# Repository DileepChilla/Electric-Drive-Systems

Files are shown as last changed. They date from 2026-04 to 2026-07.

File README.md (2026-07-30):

# 24 V / 250 W Brushed DC Motor Driver

**IR2104 half-bridge · 2× IRFZ44N · ATmega328P closed-loop control**

Design, simulation, PCB layout, firmware and bench validation of a complete motor
drive for a MY1016 24 V 250 W brushed DC motor. Built for ELT10140 *Electric Drive
Systems*, Westsächsische Hochschule Zwickau, summer semester 2026.

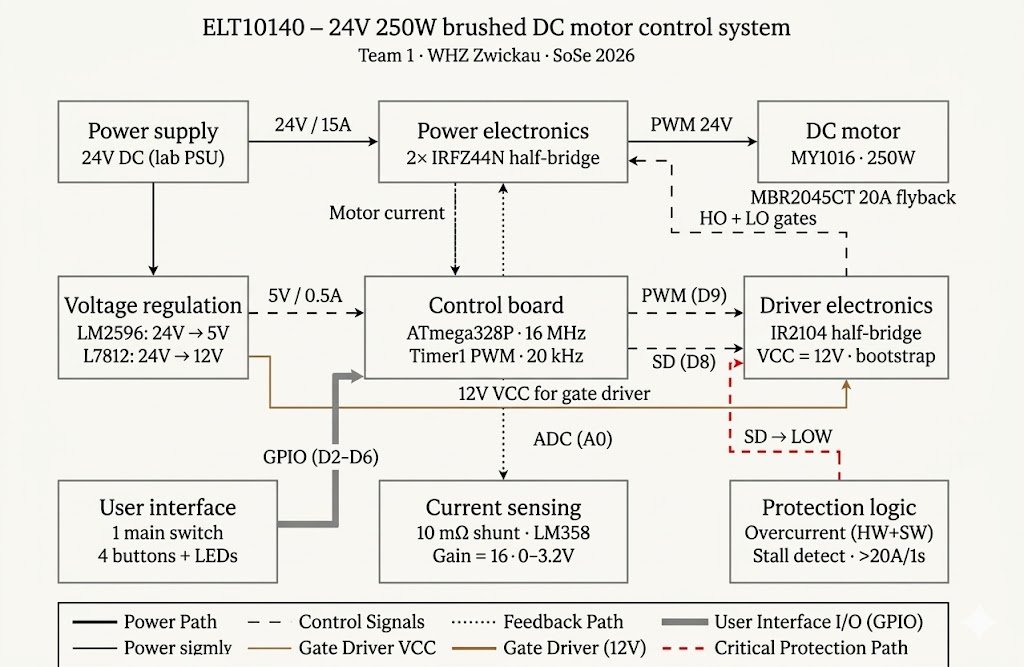
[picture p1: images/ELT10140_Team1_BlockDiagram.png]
Block diagram


---

## What this is

A single-quadrant (unidirectional) drive with hardware and software overcurrent
protection, soft-start, stall detection and a five-state supervisory state machine.
The design was carried through the full V-cycle: analytical sizing → SPICE/VSM
co-simulation → averaged-model verification in Simulink → PCB layout → assembly →
bench test.

| Metric | Value |
|---|---|
| Supply | 24 V DC, 15 A fused |
| Rated output | 250 W |
| Switching frequency | 20 kHz (Timer1 Fast PWM, ICR1 top) |
| Duty resolution | 10 bit (ICR1 = 799 @ 16 MHz, /1 prescaler) |
| Current sense | 10 mΩ shunt, ×16 non-inverting, 0–31 A → 0–5 V |
| Overcurrent trip | Hardware SD assert + firmware stall detect (> 20 A for > 1 s) |
| Board | 2-layer FR-4, 1.55 mm, 35 µm Cu |

---

## Architecture

```
24 V ──┬── LM2596 buck ──── 5 V ──── ATmega328P (Arduino Nano)
       │                                  │ OC1A (D9) ──► IN
       ├── L7812CV linear ── 12 V ────► IR2104 ──┬──► HO ──► Q1 (IRFZ44N, high side)
       │                                  ▲      └──► LO ──► Q2 (IRFZ44N, low side)
       │                            SD ───┘
       │                          (D8 + hardware fault)
       │
       └── power rail ──► Q1 drain
                          switch node ──► MY1016 motor ──► MBR2045CT ──► shunt ──► GND
                                                                          │
                                                          LM358 ×16 ──► ADC0 (A0)
```

### Design decisions worth defending

**IR2104 VCC must be 12 V, not 24 V and not 5 V.**
The device UVLO sits at ~8.2 V rising, so 5 V logic rails cannot drive it; 24 V exceeds
its absolute maximum. A dedicated L7812CV linear regulator supplies VCC. This is the
single most common way to destroy an IR2104 and the reason the design carries a second
regulator despite the buck already producing 5 V.

**Bootstrap sizing.**
1 µF ceramic + 1N4148 fast diode. At 20 kHz the high-side gate charge (Q_g ≈ 63 nC for
IRFZ44N) is replenished every 50 µs; the capacitor must hold V_BS above the 8.0 V
bootstrap UVLO across the maximum on-time. Minimum duty is clamped in firmware so the
low-side device always conducts long enough to recharge.

**Synchronous rectification over a plain flyback diode.**
Q2's channel resistance (17.5 mΩ) dissipates less than the forward drop of the Schottky
during freewheeling. The MBR2045CT remains as a parallel path covering the dead time
and as a fail-safe if the low-side gate drive is lost.

**20 kHz PWM.**
Above the audible band, below the point where IRFZ44N switching losses become the
dominant thermal term (≈ 0.35 W per device at rated current with 10 Ω gate resistors).

**Two independent overcurrent layers.**
Hardware pulls SD low in sub-microsecond time — fast enough for a short circuit.
Firmware stall detection acts on the filtered ADC current over a 1 s window — slow, but
it distinguishes a genuine mechanical jam from inrush. Neither alone is sufficient.

---

## Repository layout

```
├── firmware/          Arduino/AVR source — PWM, ADC, state machine, protection
├── hardware/
│   ├── kicad/         KiCad 10 project: schematic, PCB, footprints
│   ├── gerbers/       Fabrication output + drill files
│   └── datasheets/    Component datasheets referenced in the design
├── simulation/
│   ├── proteus/       Proteus VSM mixed-signal co-simulation (.pdsprj)
│   ├── simulink/      Averaged-model plant + discrete state machine (.slx)
│   └── results/       Captured waveforms, step responses, fault traces
├── design/            Engineering notes and derivations
├── report/            Final report (PDF) and presentation
├── bom/               Bill of materials (CSV + PDF)
└── images/            Diagrams, board photos, schematic exports
```

---

## Firmware

Bare-register AVR C++, no Arduino `analogWrite`. Timer1 in Fast PWM mode 14
(TOP = ICR1) gives a fixed 20 kHz carrier with 10-bit duty resolution.

State machine:

```
OFF ──start──► STARTING ──ramp complete──► RUNNING
 ▲                 │                          │
 │                 └──────overcurrent─────────┤
 │                                            │
 └── BRAKING ◄── stop ──────────────────────► FAULT
```

- `STARTING` ramps duty linearly to limit inrush through the motor's armature inductance.
- `FAULT` latches: SD is driven low and the state persists until an explicit reset.
- `BRAKING` shorts the armature through Q2 for dynamic braking.
- Current is read in a 4-sample exponential moving average to reject switching noise
  without adding the phase lag of a long boxcar filter.

Build: Arduino IDE or PlatformIO, target `nanoatmega328new`, 16 MHz.

---

## Simulation

**Proteus VSM** — the only tool in the chain that runs the compiled firmware against a
SPICE model of the analog stage simultaneously. Used to verify gate drive timing,
bootstrap charging, and that the ADC path actually produces the expected count for a
known shunt current.

> Note: Proteus *Analogue Analysis* is pure SPICE and does not execute the MCU
> firmware. Mixed-signal capture requires the VSM Oscilloscope instrument.
> AREF (ATmega328P pin 20) must be tied to +5 V or every ADC read returns zero and the
> overcurrent path silently fails.

**Simulink** — `MotorDriverAveraged.slx` replaces the switching stage with a duty-cycle
averaged model, letting the electrical (R–L–back-EMF) and mechanical (J–B–T_load)
dynamics run at reasonable step sizes. The firmware state machine is reimplemented in a
discrete MATLAB Function block, together with 10-bit ADC quantisation and the LM358
scaling, so the simulated controller sees the same numbers the real one does.

Two validated scenarios: light-load run-and-brake, and a rotor jam triggering the fault
path.

*Known limitation:* the load-torque model is constant rather than velocity-dependent, so
after a fault the plant shows a small reverse rotation that the real machine does not.
Documented rather than hidden — fixing it requires a Coulomb-friction/zero-speed
constraint on the mechanical block.

---

## Bill of materials

Full BOM in `bom/`. Principal parts:

| Ref | Part | Function |
|---|---|---|
| M1 | MY1016 | 24 V 250 W brushed DC motor |
| U1 | IR2104 | Half-bridge gate driver, bootstrap high-side |
| Q1, Q2 | IRFZ44N | 55 V / 49 A N-channel MOSFET, R_DS(on) 17.5 mΩ |
| D2 | MBR2045CT | 20 A Schottky freewheeling diode |
| U2 | LM358 | Current-sense amplifier, gain 16 |
| U4 | LM2596 module | 24 V → 5 V switching regulator |
| U5 | L7812CV | 24 V → 12 V linear regulator (IR2104 VCC) |
| D1 | 1N4148 | Bootstrap diode |
| — | SMBJ33A | Transient voltage suppressor, input protection |
| R_sh | 10 mΩ, 3 W | Current-sense shunt |

Mechanical: 400 × 300 × 12 mm birch plywood mounting board, ferrule-crimped
connections throughout.

---

## Reproducing

1. Open `hardware/kicad/` in KiCad 10.0 or later.
2. Flash `firmware/` to an Arduino Nano (ATmega328P, 16 MHz).
3. Supply 24 V through a 15 A fuse. **Confirm the L7812CV output is 12 V before
   connecting IR2104 VCC.**
4. Verify the switch node with an isolated probe before attaching the motor.

---

## Course context

ELT10140 Electric Drive Systems, SoSe 2026 · Westsächsische Hochschule Zwickau
Supervisors: Prof. Dr.-Ing. J. Zitzelsberger, Prof. U. David, Prof. R. Lehmann
Team 1 — Leo Kämpf (team lead), Dileep Chilla (documentation, simulation, PCB),
Vaibhav, Rahul, Shashank, Usman, Vaishali, Laert

Course handouts and lecture material are the property of WHZ and are not redistributed
in this repository.

## Licence

Source code and design files: MIT (see `LICENSE`).
Documentation and figures: CC BY 4.0.

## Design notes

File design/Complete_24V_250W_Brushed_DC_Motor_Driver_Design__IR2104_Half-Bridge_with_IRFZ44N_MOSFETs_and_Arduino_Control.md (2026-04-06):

# Complete 24V 250W brushed DC motor driver design

**The IR2104 + dual IRFZ44N half-bridge forms a synchronous buck topology that delivers clean, efficient PWM drive to the MY1016 motor — but several component-level corrections are critical before building.** The original parts list contains two significant errors: the 1N5822 Schottky diode is rated only 3A (far below the 13.7A motor current), and a single IRFZ44N cannot work with the IR2104, which drives a high-side/low-side MOSFET pair. Additionally, the IR2104 requires **10–20V on its VCC pin**, meaning a dedicated 12V regulator is needed beyond the LM2596 5V module. This report provides every component value, calculation, code listing, and layout rule needed to build an error-free motor driver PCB for the ELT10140 project at WHZ Zwickau.

---

## How the IR2104 half-bridge actually works

The IR2104 is not a simple gate buffer — it is a **complementary half-bridge driver** with built-in 520 ns deadtime. Two N-channel IRFZ44N MOSFETs form the half-bridge: Q1 (high-side, drain to +24V) and Q2 (low-side, source to GND). The motor connects between the switching node (junction of Q1 source and Q2 drain) and ground.

**Operating sequence at each PWM cycle:**

When IN goes HIGH, Q2 turns off first, 520 ns of deadtime passes, then Q1 turns on. Current flows from +24V through Q1 into the motor. When IN goes LOW, Q1 turns off, deadtime passes, then Q2 turns on. The motor's inductive current now freewheels through Q2's channel at very low loss (synchronous rectification). The average motor voltage equals **duty cycle × 24V**, giving smooth, linear speed control from 0 to ~23V.

The SD (shutdown) pin provides emergency stop capability. **SD = HIGH enables the driver; SD = LOW forces both outputs off.** A 10 kΩ pull-down resistor on SD ensures the driver powers up disabled — a critical safety feature the Arduino must explicitly override by driving SD HIGH.

**Pin connections (IR2104 in 8-DIP):**

| Pin | Symbol | Connects to |
|-----|---|---|
| 1 | VCC | +12V regulated supply |
| 2 | IN | Arduino Pin D9 (Timer1 OC1A PWM) |
| 3 | SD | Arduino Pin D8 via 10 kΩ pull-down to GND |
| 4 | COM | Power ground (GND) |
| 5 | LO | Q2 gate through 10 Ω resistor |
| 6 | VS | Switching node (Q1 source / Q2 drain) |
| 7 | HO | Q1 gate through 10 Ω resistor |
| 8 | VB | Bootstrap capacitor to VS; bootstrap diode from VCC |

No level shifting is needed. The IR2104 accepts 5V logic directly (VIH ≥ 3.0V, VIL ≤ 0.8V). Input bias current is just 3–10 µA, negligible for Arduino GPIO.

---

## Complete schematic with every component value

### Power stage

The heart of the circuit is the half-bridge formed by two IRFZ44N MOSFETs. **You need two IRFZ44N devices, not one.** Q1 serves as the high-side switch (drain to +24V, source to switching node), Q2 as the low-side switch (drain to switching node, source to GND through the current sense resistor).

**Bulk capacitor on 24V rail:** 470 µF / 50V electrolytic in parallel with 100 nF / 50V ceramic, placed directly at the power input connector. These handle the high di/dt current pulses during PWM switching. Without them, voltage spikes during switching can exceed the IRFZ44N's 55V drain-source rating.

**Gate resistors:** 10 Ω in series with each gate (between IR2104 HO→Q1 gate and LO→Q2 gate). These damp LC ringing from gate trace inductance and MOSFET input capacitance. Values above 100 Ω slow switching dangerously; values below 5 Ω may cause ringing. A **10 kΩ pull-down resistor from each gate to its respective source** ensures MOSFETs stay off if the IR2104 loses power.

### Bootstrap circuit

The bootstrap circuit charges a capacitor (C_boot) when Q2 is ON (VS pulled to ground), then uses that stored energy to drive Q1's gate above the 24V rail.

**Bootstrap capacitor calculation (worst case):**

The charge consumed per switching cycle includes the IRFZ44N gate charge (Qg = 63 nC max), the IR2104 quiescent VBS current (55 µA max at 20 kHz = 2.75 nC), and level-shift charge (~5 nC). Total per-cycle charge is approximately **71 nC**. The minimum capacitor value follows the formula C_boot ≥ 2 × Q_total / ΔV, where ΔV = VCC − V_diode − V_LS_drop − V_UVLO_min = 12 − 0.5 − 0.24 − 8.2 = 3.06V. This yields C_min ≈ 46 nF. Applying the standard **15× safety factor** gives 690 nF.

**Use a 1 µF ceramic capacitor (MLCC, X7R, 50V rated)** between VB and VS. This value appears consistently across Infineon application notes, verified project implementations, and the AN-978 design guide. Do not use electrolytic capacitors — their ESR and leakage are too high for bootstrap service.

**Bootstrap diode: UF4007** (1000V, 1A, ultra-fast recovery, 75 ns trr). This connects anode to VCC (+12V), cathode to VB. The 1000V rating provides enormous margin over the 24V bus. A fast recovery diode is essential — a slow diode allows charge to flow backward out of the bootstrap capacitor during VS transitions, starving the high-side gate drive. Alternative: MBR160 (60V Schottky) for lower forward voltage drop (0.5V vs 1.0V), though the UF4007's wider voltage margin is preferred for a student project.

The resulting high-side gate voltage is approximately VCC − V_diode_drop = 12 − 0.5 ≈ **11.5V** (with Schottky) or 12 − 1.0 ≈ **11V** (with UF4007). Both fully enhance the IRFZ44N well above the 10V specification point.

**Maximum duty cycle limitation:** The bootstrap capacitor recharges only when Q2 is ON. At 95% duty and 20 kHz (50 µs period), Q2 conducts for 2.5 µs — sufficient to recharge 1 µF through the low-impedance path. At 99%+ duty, on-time drops below 0.5 µs and the capacitor may not fully recharge. **Practical limit: ~95–97% duty cycle.**

### IR2104 VCC supply

The IR2104 requires **10–20V on VCC**. The LM2596 module providing 5V to the Arduino cannot serve this purpose. Add a separate **L7812 (or LM7812) linear regulator**: 24V input → 12V output. Bypass the regulator with 100 nF ceramic on both input and output, plus 10 µF electrolytic on the output. At the IR2104's modest current draw (~1 mA quiescent plus gate charge current), the 7812's dissipation is approximately (24 − 12) × 0.01 ≈ 0.12W — negligible.

**VCC decoupling at the IR2104:** Place a **100 nF ceramic capacitor directly between VCC (pin 1) and COM (pin 4)**, within 5 mm of the IC. Add a **10 µF electrolytic in parallel**, slightly further away. This dual-capacitor arrangement handles both high-frequency switching transients (ceramic) and lower-frequency supply droop (electrolytic).

### Current sensing circuit

A low-side shunt resistor between Q2's source and power ground measures motor current. The voltage across this shunt is amplified by one half of the LM358 dual op-amp.

**Shunt resistor: 10 mΩ (0.010 Ω), rated 5–10W.** Use a metal-strip type (Vishay WSL2512 in 2512 SMD or Ohmite 25FR010 through-hole wirewound). At 13.7A rated current, V_shunt = 137 mV and P_shunt = 1.88W. At 27A stall, P_shunt = 7.29W. A 10W-rated resistor survives brief stalls while overcurrent protection activates.

Why 10 mΩ? Smaller values (1–5 mΩ) produce signals below the LM358's 2–7 mV input offset voltage, causing unacceptable measurement error. Larger values (20+ mΩ) waste power and create significant voltage drops that reduce motor drive voltage.

**LM358 non-inverting amplifier (gain = 16):**

The LM358 has a critical limitation on 5V supply: **its output can only swing to approximately 3.5V maximum** (VCC − 1.5V). The design therefore maps the overcurrent threshold (20A) to 3.2V rather than 5V:

- R1 = **1.0 kΩ** (ground to inverting input)
- R2 = **15 kΩ** (feedback, inverting input to output)
- Gain = 1 + R2/R1 = 1 + 15/1 = **16**
- Use 1% metal film resistors for both

**Transfer function:** V_out = I_motor × 0.010 Ω × 16 = **0.16 × I_motor** (volts). At the Arduino's 10-bit ADC (5V reference): **ADC count = I_motor × 32.77**. Current resolution is approximately **30.5 mA per ADC count** — more than adequate for motor control.

| Motor current | Shunt voltage | LM358 output | ADC count |
|---|---|---|---|
| 0 A | 0 mV | ~0 V | 0 |
| 5 A | 50 mV | 0.80 V | 164 |
| 10 A | 100 mV | 1.60 V | 328 |
| **13.7 A (rated)** | **137 mV** | **2.19 V** | **449** |
| **20 A (OC threshold)** | **200 mV** | **3.20 V** | **655** |
| 22+ A | 220+ mV | Saturates ~3.5 V | ~720 |

Above ~22A the LM358 output clips at 3.5V. This is acceptable because overcurrent protection should trigger at 20A (ADC ≈ 655), well before saturation.

**Output filter:** A 1 kΩ resistor and **82 nF ceramic capacitor** form a low-pass filter (f_c ≈ 1.94 kHz) between the LM358 output and the Arduino analog pin. This removes PWM-frequency ripple while preserving the averaged current signal.

**ADC protection:** Place a 1 kΩ series resistor immediately before the Arduino analog pin, followed by a BAT54S Schottky diode from the pin to the 5V rail (cathode to 5V). This clamps any overvoltage from reaching the ATmega328P.

**Offset calibration:** The LM358's 2–7 mV typical offset, amplified by 16, creates a 32–112 mV output offset (equivalent to 0.2–0.7A error). **Calibrate in software** by reading the ADC at zero motor current during startup and subtracting this baseline.

### Corrected flyback / freewheeling diode

**The 1N5822 Schottky diode is rated only 3A average forward current — it is fundamentally inadequate for a 13.7A motor.** In the half-bridge topology, during the 520 ns deadtime between Q1 turning off and Q2 turning on, the motor's inductive current freewheels through Q2's body diode. An external Schottky diode across Q2 (anode to source/GND, cathode to drain/switching node) provides a lower-loss freewheeling path during deadtime.

**Replace the 1N5822 with an MBR2045CT** (20A, 45V dual Schottky in TO-220) or equivalent. Use one diode of the dual package across Q2. The 20A rating provides margin above the 13.7A operating current, and the 45V rating exceeds the 24V bus with comfortable margin.

The 1N5822 could still serve as the bootstrap diode alternative or for auxiliary protection circuits, but must not carry motor current.

### Buttons and indicators

Use Arduino's internal pull-ups (INPUT_PULLUP) for buttons: connect each button between the GPIO pin and GND. Press reads LOW. Software debounce at 50 ms eliminates bounce without external RC networks.

- **Start button:** Pin D2 → GND
- **Stop button:** Pin D3 → GND  
- **Fault reset button:** Pin D5 → GND

**LED indicators:** Green LED (motor running) on pin D6, red LED (fault) on pin D7, each with a **330 Ω series resistor** to ground. Pin D13's onboard LED serves as a heartbeat indicator.

### Complete bill of materials

| Component | Value / Part | Rating | Purpose |
|---|---|---|---|
| IR2104 | Infineon, 8-DIP | 600V half-bridge driver | Gate driver IC |
| IRFZ44N × **2** | Infineon, TO-220 | 55V, 49A, 17.5 mΩ | High-side and low-side MOSFETs |
| C_boot | 1 µF ceramic MLCC | 50V, X7R | Bootstrap capacitor (VB–VS) |
| D_boot | UF4007 | 1000V, 1A, ultra-fast | Bootstrap diode (VCC→VB) |
| C_VCC_HF | 100 nF ceramic | 25V | IR2104 VCC bypass (close to IC) |
| C_VCC_bulk | 10 µF electrolytic | 25V | IR2104 VCC decoupling |
| C_bus_bulk | 470 µF electrolytic | 50V | 24V bus decoupling |
| C_bus_HF | 100 nF ceramic | 50V | 24V bus HF bypass |
| D_freewheel | **MBR2045CT** | 20A, 45V Schottky | Across Q2 (freewheeling) |
| R_gate × 2 | 10 Ω | ¼W | Series gate resistors |
| R_GS × 2 | 10 kΩ | ¼W | Gate-source pull-downs |
| R_SD | 10 kΩ | ¼W | SD pin pull-down to GND |
| 7812 regulator | L7812CV | 24V→12V, 1A | IR2104 VCC supply |
| C_reg_in | 100 nF ceramic | 50V | 7812 input bypass |
| C_reg_out | 10 µF electrolytic | 25V | 7812 output filter |
| R_shunt | 10 mΩ, metal strip | 5–10W | Current sense resistor |
| LM358 | Dual op-amp, 8-DIP | 5V supply | Current amplifier |
| R1 (gain) | 1.0 kΩ, 1% | ¼W | Amplifier gain network |
| R2 (gain) | 15 kΩ, 1% | ¼W | Amplifier gain network |
| R_filter | 1.0 kΩ | ¼W | Output low-pass filter |
| C_filter | 82 nF ceramic | 25V | Output low-pass filter |
| R_protect | 1.0 kΩ | ¼W | ADC input series protection |
| D_clamp | BAT54S | Schottky clamp | ADC overvoltage protection |
| LM2596 module | 24V→5V buck | 3A | Arduino power supply |
| Buttons × 3 | Tactile switch | — | Start, stop, reset |
| LEDs × 2 | Green, red | 20 mA | Run, fault indicators |
| R_LED × 2 | 330 Ω | ¼W | LED current limiting |

---

## Critical errors that destroy student motor drivers

### The number-one killer: driving IRFZ44N directly from Arduino

The IRFZ44N's VGS(th) of 2–4V is the voltage where conduction *barely begins* — at microamp levels. Full enhancement (17.5 mΩ) requires VGS ≥ 10V. **At VGS = 5V from an Arduino pin, RDS(on) rises to an estimated 100–200 mΩ**, roughly 10× higher than the datasheet value. At 10A, power dissipation jumps from 1.75W to **10–20W** — the MOSFET enters thermal runaway and fails within seconds. The IR2104, powered at 12V VCC, delivers approximately 11–12V to each gate, achieving full enhancement. This is the entire reason a gate driver exists.

If the project requires direct Arduino drive without a gate driver (a simpler approach), replace the IRFZ44N with the **IRLZ44N** (logic-level variant, fully enhanced at VGS = 5V). But with the IR2104 in the design, stick with the standard IRFZ44N.

### Bootstrap failures that cause intermittent operation

Three bootstrap errors account for most IR2104 field failures in student projects. First, **a capacitor below ~100 nF** cannot supply the IRFZ44N's 63 nC gate charge with adequate margin, causing VBS to droop below the 8.2V UVLO threshold. The high-side MOSFET then enters linear mode at partial gate drive, dissipating enormous power. Second, **using a slow-recovery diode** (e.g., 1N4007 instead of UF4007) allows bootstrap charge to leak back into VCC during reverse recovery, depleting the capacitor. Third, **running at 100% duty cycle** prevents Q2 from ever turning on, so the bootstrap capacitor never recharges — the high-side gate drive collapses within milliseconds.

### Decoupling capacitor omissions

Without the 100 nF ceramic directly at VCC (pin 1), the IR2104 experiences voltage transients during gate switching that can trigger false UVLO lockout, causing random gate drive dropouts. Without bulk capacitance (470 µF) on the 24V bus near the MOSFETs, inductive voltage spikes during switching can exceed the IRFZ44N's 55V absolute maximum, causing avalanche breakdown and eventual failure.

### PWM frequency from default analogWrite()

Arduino's `analogWrite()` produces **490 Hz on pins 9/10 and 976 Hz on pins 5/6** — both audibly annoying and electrically poor. Low-frequency PWM creates massive current ripple, increases I²R losses in the motor windings, and causes jerky operation at low speeds. **Always configure Timer1 directly for 20 kHz**, as detailed in the software section below.

### The SD pin left floating

The IR2104's SD pin, if left unconnected, floats at an undefined voltage. This causes random enable/disable behavior and erratic motor operation. **Always include a 10 kΩ pull-down** to GND for power-up safety, and drive it HIGH from an Arduino GPIO to enable the driver.

---

## Power dissipation, thermal analysis, and stall behavior

### Conduction and switching losses per MOSFET

At **13.7A rated current** with RDS(on) = 17.5 mΩ (25°C), conduction loss is I²R = 13.7² × 0.0175 = **3.28W**. At elevated junction temperature (~100°C), RDS(on) rises by approximately 1.5× to ~26 mΩ, increasing conduction loss to **4.93W**. Switching losses at 20 kHz add P_sw = 0.5 × 24V × 13.7A × (60 ns + 45 ns) × 20 kHz ≈ **0.35W**. Total dissipation per MOSFET under continuous rated load is approximately **3.6W at 25°C, rising to 5.3W at operating temperature**.

### Heatsink sizing

Without any heatsink, the IRFZ44N's junction-to-ambient thermal resistance is 62°C/W. At 3.6W, the junction temperature rise is 223°C above ambient — **catastrophic failure is guaranteed**. A heatsink is mandatory for each MOSFET.

For a target junction temperature of 125°C with 40°C ambient and 5.3W dissipation: required total thermal resistance = (125 − 40) / 5.3 = 16.0°C/W. Subtracting RθJC (1.5°C/W) and RθCS (0.5°C/W with thermal compound), the heatsink must provide **RθSA ≤ 14°C/W**. A small clip-on TO-220 aluminum heatsink (~25 × 20 × 15 mm) achieves approximately 12–15°C/W, which is sufficient. **No fan is needed at rated 13.7A current with a modest heatsink.**

**Critical note on shared heatsinks:** The IRFZ44N TO-220 metal tab is connected to the drain. Q1's tab sits at +24V, Q2's tab at the switching node (0–24V). If both MOSFETs share a single heatsink, **insulating thermal pads are mandatory** between each tab and the heatsink to prevent a short circuit.

### Motor stall scenario

A stalled MY1016 motor with its low winding resistance (~24V / 27A ≈ 0.89 Ω) draws approximately **27A** at full duty. Power dissipation per MOSFET at stall: 27² × 0.0175 = **12.8W at 25°C**, rising to ~19W at elevated temperature. Even with a good heatsink (5°C/W), junction temperature reaches 40 + 19 × 7 = **173°C — at the absolute maximum rating**. Without active cooling, the MOSFET survives only seconds.

The motor stall time constant (L/R ≈ 2 mH / 0.89 Ω ≈ 2.25 ms) means current reaches 63% of stall value in ~2.3 ms and 95% in ~7 ms. **The overcurrent protection must respond within a few milliseconds.** This is why hardware-based protection (analog comparator driving SD LOW) is essential — software ADC polling at 100–500 µs response time is too slow.

### Voltage drop and efficiency

At 13.7A, the voltage drop across each conducting MOSFET is just **I × RDS(on) = 13.7 × 0.0175 = 0.24V**. With a 10 mΩ shunt adding another 0.14V, total losses in the power path amount to approximately 0.38V — the motor sees 24 − 0.38 ≈ **23.6V at full duty**, for an efficiency above 98% in the power stage alone.

---

## PCB layout for a reliable 2-layer motor driver

A **2-layer PCB with 2 oz (70 µm) copper** is sufficient for this 250W driver when designed carefully. The key constraint is trace width: at 13.7A continuous on an external 2 oz copper layer with 20°C temperature rise, IPC-2221 specifies a minimum trace width of approximately **3.7 mm**. Adding 50% safety margin and accounting for brief stall currents, **target 5–8 mm trace width for all power paths** (24V rail, ground return, switching node, motor output).

### Component placement rules

Place the IR2104 within **10–15 mm of both MOSFET gates**. Gate traces must be short, wide (≥ 0.5 mm), and routed as adjacent forward/return paths to minimize loop inductance. The 10 Ω gate resistors sit directly at the MOSFET gate pins. The 100 nF VCC decoupling capacitor goes within 3–5 mm of IR2104 pins 1 and 4. The 1 µF bootstrap capacitor goes within 3–5 mm of pins 8 (VB) and 6 (VS).

The **power loop** — from the bulk capacitor positive terminal, through Q1, through Q2, back to the bulk capacitor negative terminal — must be as physically small as possible. Parasitic inductance in this loop creates voltage spikes proportional to L × di/dt. With 20 kHz switching and 13.7A current, even a few nanohenries of loop inductance generates significant spikes.

### Grounding strategy

Use a **partitioned star-ground approach** on the 2-layer board. Dedicate the bottom copper layer primarily as a **continuous GND copper pour**. The power ground return (Q2 source → shunt resistor → bulk capacitor negative) runs on wide top-layer traces or pours. Signal ground (Arduino, LM358, ADC) connects to the ground plane through a separate path, meeting the power ground at a single star point near the bulk capacitor.

Route current sense traces as a differential pair (Kelvin connection to shunt resistor) on the opposite side of the board from the switching node. Keep these analog traces away from the high di/dt power traces to prevent coupled noise.

### Thermal via strategy for MOSFETs

Under each IRFZ44N drain pad, place **6–12 thermal vias** (0.3 mm drill, 0.6 mm pad) connecting to a large copper pour on the bottom layer. Use **direct connections (no thermal relief)** for these vias — thermal relief pads reduce heat transfer. Extend the copper pour around and beneath each MOSFET to at least 10× the pad area for heat spreading.

### Connectors

Use **screw terminal blocks rated ≥ 20A** (5.08 mm pitch, Phoenix Contact MKDS series or equivalent) for both the motor output and 24V power input. Standard 2.54 mm female pin headers accept the Arduino Nano. Consider XT60 connectors for the power input — rated 60A continuous, widely available, and provide reliable high-current connection and disconnection.

### KiCad-specific setup

In Board Setup → Design Rules → Net Classes, create three classes: **Signal** (0.3–0.5 mm track, 0.25 mm clearance), **Gate** (0.5–1.0 mm track, 0.3 mm clearance), and **Power** (5.0–8.0 mm track, 0.5 mm clearance). Assign motor power nets (+24V, GND, switching node) to the Power class. Add predefined track widths (0.3, 0.5, 1.0, 2.5, 5.0, 8.0 mm) for quick selection during routing. Use `Package_DIP:DIP-8_W7.62mm` for the IR2104 and `Package_TO_SOT_THT:TO-220-3_Vertical` for the IRFZ44N with vertical heatsink mounting. Run DRC before generating Gerbers — check for clearance violations and unconnected nets.

---

## Arduino software: Timer1 PWM, current sensing, and protection

### 20 kHz PWM generation on Timer1

The ATmega328P's 16-bit Timer1 outputs PWM on **Pin D9 (OC1A)**. Using Fast PWM Mode 14 with ICR1 as TOP and no prescaler: TOP = 16,000,000 / (1 × 20,000) − 1 = **799**, giving exactly 20.000 kHz with 800 discrete duty cycle steps (~9.6-bit resolution).

```cpp
void setupTimer1_20kHz() {
    // Pin 9 (OC1A) as output
    DDRB |= (1 << PB1);
    
    // Reset Timer1
    TCCR1A = 0;
    TCCR1B = 0;
    TCNT1  = 0;
    
    // Fast PWM Mode 14: WGM13:10 = 1110
    // Non-inverting output on OC1A (Pin 9)
    TCCR1A = (1 << COM1A1) | (1 << WGM11);
    TCCR1B = (1 << WGM13) | (1 << WGM12) | (1 << CS10);
    
    // TOP = 799 → f_PWM = 16MHz / (1 × 800) = 20,000 Hz
    ICR1  = 799;
    OCR1A = 0;  // Start at 0% duty
}

// Set duty cycle: 0 = off, 799 = ~100%
void setDuty(uint16_t duty) {
    OCR1A = (duty > 799) ? 799 : duty;
}
```

**Never use `analogWrite()`** for this motor driver. Its default 490 Hz output causes audible whine, excessive current ripple, and poor low-speed control.

### Current measurement with exponential moving average

```cpp
#define CURRENT_PIN    A0
#define SHUNT_R        0.010   // 10 mΩ
#define AMP_GAIN       16.0
#define VREF           5.0
#define ADC_SCALE      (VREF / 1024.0 / (SHUNT_R * AMP_GAIN))

float filteredCurrent = 0.0;
int   zeroOffset      = 0;     // Calibrated at startup

void calibrateCurrentSensor() {
    long sum = 0;
    for (int i = 0; i < 64; i++) {
        sum += analogRead(CURRENT_PIN);
        delay(1);
    }
    zeroOffset = sum / 64;
}

float readCurrent() {
    int raw = analogRead(CURRENT_PIN) - zeroOffset;
    if (raw < 0) raw = 0;
    float current = raw * ADC_SCALE;  // ≈ 0.0305 A per count
    filteredCurrent = 0.1 * current + 0.9 * filteredCurrent;
    return filteredCurrent;
}
```

### Hardware overcurrent protection using the analog comparator

The ATmega328P's built-in analog comparator provides **~2–5 µs response** — orders of magnitude faster than ADC polling. Configure it to compare the 1.1V internal bandgap reference against the amplified current sense voltage on AIN1 (Pin D7). At gain 16 with 10 mΩ shunt, 1.1V corresponds to approximately **6.9A** — too low for a 13.7A motor.

**Better approach:** Use the second LM358 op-amp channel as a dedicated **hardware comparator**. Set its non-inverting input to a reference voltage (voltage divider: 3.2V for 20A threshold). Connect its inverting input to the current amplifier output. The LM358's open-collector-compatible output drives the IR2104 SD pin LOW through a diode when current exceeds the threshold. This provides **sub-microsecond hardware shutdown with zero CPU involvement**.

For the software backup, use the analog comparator ISR with the amplified signal routed to AIN1:

```cpp
#define SD_PIN 8

volatile bool overcurrentFault = false;

void setupOvercurrentISR() {
    // Use bandgap (1.1V) as positive input,
    // AIN1 (Pin 7) as negative input
    ACSR = (1 << ACBG)    // Bandgap reference on AIN+
         | (1 << ACI)     // Clear pending interrupt
         | (1 << ACIE)    // Enable interrupt
         | (1 << ACIS1);  // Falling edge (AIN1 > 1.1V)
}

ISR(ANALOG_COMP_vect) {
    PORTB &= ~(1 << PB0);     // SD pin LOW (fast port write)
    OCR1A = 0;                 // Kill PWM immediately
    overcurrentFault = true;
}
```

### State machine for motor control

The motor controller operates in five states: **OFF → STARTING → RUNNING → BRAKING → OFF**, with any active state transitioning to **FAULT** on overcurrent or stall detection.

**Stall detection logic:** If filtered current exceeds **20A** (2× rated, ADC > 655) continuously for more than **1 second**, the controller declares a stall fault and shuts down. This time window prevents false triggers from normal startup inrush or transient loads, while protecting the MOSFETs from sustained thermal overload.

**Soft-start:** During the STARTING state, PWM duty ramps linearly from 0 to target over **2 seconds**. This limits inrush current and reduces mechanical stress on the motor and load.

```cpp
enum State { OFF, STARTING, RUNNING, BRAKING, FAULT };
State state = OFF;
unsigned long stateEntry = 0;
unsigned long stallTimer = 0;
bool stallActive = false;

void updateMotor() {
    unsigned long now = millis();
    float current = readCurrent();
    
    switch (state) {
    case OFF:
        OCR1A = 0;
        if (startPressed()) {
            digitalWrite(SD_PIN, HIGH);
            state = STARTING;
            stateEntry = now;
        }
        break;
        
    case STARTING: {
        unsigned long elapsed = now - stateEntry;
        uint16_t duty = (elapsed < 2000)
            ? (uint16_t)((uint32_t)799 * elapsed / 2000)
            : 799;
        setDuty(duty);
        if (elapsed >= 2000) { state = RUNNING; stateEntry = now; }
        if (overcurrentFault) { enterFault(); }
        break;
    }
    
    case RUNNING:
        // Stall detection: >20A for >1 second
        if (current > 20.0) {
            if (!stallActive) { stallActive = true; stallTimer = now; }
            else if (now - stallTimer > 1000) { enterFault(); }
        } else { stallActive = false; }
        if (stopPressed()) { state = BRAKING; stateEntry = now; }
        if (overcurrentFault) { enterFault(); }
        break;
        
    case BRAKING: {
        unsigned long elapsed = now - stateEntry;
        setDuty((elapsed < 1000) ? 799 - (uint16_t)(799UL * elapsed / 1000) : 0);
        if (elapsed >= 1000) { state = OFF; }
        break;
    }
    
    case FAULT:
        OCR1A = 0;
        digitalWrite(SD_PIN, LOW);
        if (resetPressed()) {
            overcurrentFault = false;
            state = OFF;
        }
        break;
    }
}
```

The main `loop()` calls `updateMotor()` continuously alongside rate-limited serial debugging (every 250 ms) and LED updates. The entire architecture is non-blocking — **no `delay()` calls anywhere**.

---

## Conclusion

This motor driver design centers on a synchronous half-bridge topology that is fundamentally more efficient than a simple low-side switch with flyback diode, because Q2's channel (17.5 mΩ) provides a far lower-loss freewheeling path than any diode. The three corrections to the original parts list — **adding a second IRFZ44N, replacing the 1N5822 with a 20A-rated MBR2045CT, and adding a 7812 regulator for IR2104 VCC** — are non-negotiable; without them, the circuit either cannot function or will fail under load.

The thermal analysis reveals a comfortable margin at rated current (junction temperature ~77°C with a decent heatsink) but dangerously narrow margin during stall (~173°C). This makes the dual-layer overcurrent protection — hardware comparator on the SD pin for sub-microsecond response plus software stall detection for slower overcurrent events — the most safety-critical part of the entire design. The 20 kHz PWM frequency, generated by Timer1 in Fast PWM Mode 14, eliminates audible noise while keeping switching losses below 0.35W per MOSFET. Finally, the 2-layer PCB with 2 oz copper and 5–8 mm power traces can handle the full 13.7A rated current with modest temperature rise, provided the gate driver sits within 15 mm of the MOSFET gates and the power loop area is minimized.

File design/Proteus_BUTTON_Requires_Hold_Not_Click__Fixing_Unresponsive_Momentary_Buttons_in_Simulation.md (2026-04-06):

# Proteus BUTTON requires hold, not click

**The BUTTON component in Proteus is momentary — it only closes the circuit while you hold the left mouse button down, and springs open the instant you release.** This almost certainly explains why "subsequent clicks don't work": every quick click-and-release produces only a brief pulse identical to the first, and without proper pull-up resistors the ATmega328P pin floats at its previous voltage after release, making it appear stuck. The fix is either to hold the mouse button down for the full press duration, switch to a SWITCH component for toggle behavior, or add pull-up resistors to prevent floating pins.

## The BUTTON is momentary, not a toggle

The BUTTON component (SPST push button from the ACTIVE library) in Proteus ISIS simulates a real-world momentary tactile push button — like a doorbell. During VSM simulation, you must **left-click and hold** the mouse button down on the component to keep the circuit closed. The moment you release the mouse, the button springs back to its open (default) state. There is no toggle behavior whatsoever.

This is the critical misunderstanding. When a user performs a quick click-and-release, the button closes for only a tiny fraction of simulation time, then immediately reopens. The first click appears to "work" because the ATmega328P detects the brief LOW pulse. But subsequent clicks produce the exact same brief pulse — the button isn't failing to respond; it's responding identically each time with an extremely short closure that may be too brief for the firmware to detect, or the pin's floating state after release masks the change.

No special keyboard shortcut, spacebar press, or right-click action is needed. **Left-click and hold** is the only interaction method for momentary buttons. No "active component mode" or interaction mode toggle exists — active components respond to mouse input automatically during a running simulation.

## BUTTON vs SWITCH: two fundamentally different components

| Feature | BUTTON (Momentary) | SWITCH (Latching) |
|---|---|---|
| Interaction | Left-click **and hold** | Single left-click to **toggle** |
| Behavior | Closed only while held; opens on release | Stays in last position until clicked again |
| Real-world analog | Doorbell, tactile push button | Wall light switch, toggle switch |
| Best for | Brief pulse inputs, interrupt triggers | ON/OFF state control, mode selection |

If the goal is to click once to close the circuit and click again to open it, the correct component is a **SWITCH** (SPST, SPDT, etc. from the ACTIVE library), not a BUTTON. Alternatively, the **LOGICSTATE** interactive component provides a clean digital HIGH/LOW toggle that multiple experienced Proteus users recommend as more reliable for microcontroller input testing.

## Floating pins create the illusion of a stuck button

A second factor compounds the confusion. When the BUTTON opens (mouse released), the ATmega328P input pin becomes electrically disconnected. Without a pull-up or pull-down resistor, the pin **floats** — and Proteus models stray capacitance on floating nodes, causing the pin to retain its previous voltage. The visual wire-color indicator stays red (high/active) even though the button is open, making it look like the button is stuck in its pressed state.

The fix is straightforward. Add a **10kΩ pull-up resistor** from the MCU pin to VCC (for active-LOW buttons where the button pulls to GND), or configure `pinMode(buttonPin, INPUT_PULLUP)` in Arduino code. This ensures the pin returns cleanly to a defined HIGH state when the button is released, and subsequent press-and-hold actions will produce clear, detectable LOW transitions.

## CPU overload can swallow button clicks entirely

Even with correct interaction technique, Proteus may miss button clicks when the simulation is **not running in real time** due to excessive CPU load. This is the second most common cause of unresponsive interactive components. The status bar at the bottom of the Proteus window displays a warning when this occurs. Proteus is single-threaded, so multi-core processors don't help.

Several circuit design choices dramatically worsen CPU load and should be avoided:

- **External crystal oscillators wired on the schematic** create an extremely fast analog oscillation loop that bottlenecks everything. Set the MCU clock frequency in the component's properties dialog instead (right-click → Edit Properties), and either remove the crystal or mark it "Exclude from simulation."
- **Analog resistor models** instead of digital ones, particularly for I2C pull-ups and LED current limiters, add unnecessary computational overhead.
- **Animation features** like wire voltage coloring and current flow arrows consume significant CPU. Disable these under System → Set Animation Options if responsiveness is poor.
- **Reducing Frames Per Second** in animation options lowers display overhead and frees CPU cycles for processing input events.

## No Proteus 9 bug — but verify the ACTIVE library source

No specific Proteus 9 bug affecting BUTTON interaction was found in Labcenter's documentation, forums, or known issue databases. The behavior is consistent across Proteus versions and reflects the intentional momentary-action design of the component.

However, one critical verification step: the BUTTON **must** come from the **ACTIVE** library column in the Pick Devices dialog. Non-active versions of the same component exist for schematic and PCB design only — they look identical on the schematic but will not respond to any mouse interaction during simulation. Double-check this by opening the component's properties and confirming it references the ACTIVE library. Demo or evaluation versions of Proteus may also restrict interactive simulation functionality.

## Conclusion

The root cause is almost certainly a mismatch between expected toggle behavior and the BUTTON's actual momentary behavior. Three concrete actions resolve the issue: **hold the left mouse button down** for the full duration of each press instead of quick-clicking; **add a 10kΩ pull-up resistor** (or use `INPUT_PULLUP`) to prevent floating pins from masking state changes; and if toggle behavior is truly desired, **replace the BUTTON with a SWITCH or LOGICSTATE component**. If clicks still feel unresponsive after these changes, check the status bar for CPU overload warnings and reduce simulation overhead by removing crystal oscillators from the schematic, switching to digital component models, and disabling animation features.

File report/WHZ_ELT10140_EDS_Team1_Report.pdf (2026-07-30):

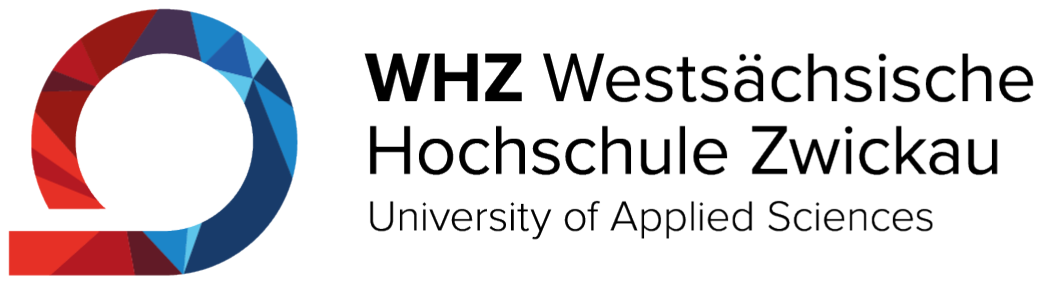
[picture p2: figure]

## WESTSÄCHSISCHE HOCHSCHULE

## ZWICKAU

FACULTY OF ELECTRICAL ENGINEERING

MASTER OF SCIENCE IN EMBEDDED SYSTEMS AND AUTONOMOUS SYSTEMS

Interim Project Documentation

### 24V / 250W BRUSHED DC MOTOR DRIVER

Summer Semester 2025–2026

SUPERVISORS:

Prof. Dr.-Ing. Johann Zitzelsberger Mr. Uwe David
Mr. Ringo Lehmann

TEAM 1 – CANDIDATES:

Leonard Kämpf | (Team Leader)
Dileep Chilla | (Documentation)
Shashank Raja (Software)
Vaibhav (PCB)
Rahul Kosanam (Hardware)
Usman
Vaishali Heer
Laert Alushaj (Testing & Validation)

Course: ELT10140 – Practical Course in Electric Drive Systems

# Abstract

# Contents

1 Introduction | 1
2 Circuit Design | 5
3 Software Design | 22
4 Conclusion and Outlook | 27
A Appendix | 30

# List of Figures

2.1 Complete schematic of the 24 V / 250W brushed DC motor driver (KiCad
export) | 5
2.2 Input protection section of the schematic: screw terminals J1 and J2, 15 A
fuse F1, and TVS diode D1 (SMBJ33A) | 7
2.3 Linear voltage regulator section: L7812CV (U1) with input capacitor C4 (330 nF), output capacitors C5 (10 µF) and C6 (100 nF), power-on indicator
LED D2 with series resistor R1 (1 kΩ) | 9
2.4 Gate driver and bootstrap circuit: IR2104 (U3) with VCC decoupling capacitors C8 (1 µF) and C9 (100 nF), bootstrap diode D3 (BAS 16J) and bootstrap
capacitor C10 | 11
2.5 Half-bridge power stage: high-side MOSFET Q1 and low-side MOSFET Q2 (IRFZ44N) with gate resistors R2, R4 (10 Ω) and gate pull-down resistors R3,
R5 (10 kΩ) | 11
2.6 Buck converter module and OLED display connector: LM2596 module at
J3 (24 V → 5 V), local decoupling capacitor C20 (1 µF) and OLED display
connector J10 (SSD1306, I²C) | 12
2.7 Current sensing circuit: motor output connector J4 with freewheeling diode
D4 (MBR2045CT), low-side shunt resistor R6 (10 mΩ, 3W), LM358 non-inverting amplifier (U2A, gain = 16) with input filter C11, feedback resistors
R8 and R9, ADC protection resistor R10 (100 Ω) and Zener diode D5 (5.1 V).
Channel B (U2B) is configured as a unity-gain buffer | 13
2.8 Control board and user interface: Arduino Nano (A1, ATmega328P) with button connectors J5–J8 (OFF, Speed-Up, Speed-Down, ON), ISP header J9, status LEDs D6 (power), D7 (fault) and D8 (run) with 330 Ω current-limiting
resistors R11, R12 and R13 | 14
2.9 Estimated steady-state component temperatures for the nominal operating
point | 16
2.10 Transient temperature response using independent first-order thermal models. 16 2.11 Influence of the motor current on the estimated steady-state temperature of
the main power components | | 17
2.12 Influence of the PWM frequency on the estimated MOSFET temperature. . . | 17
2.13 Influence of the duty cycle on the estimated steady-state temperature of the
main power components | | 18
2.14 Transient thermal response of the simplified PCB-coupled thermal network. . | 19
2.15 PCB layout of the DC motor driver showing the arrangement of the power
stage, input capacitors and control electronics | | 20
3.1 Simplified sequence diagram of the embedded motor control software | | 22
3.2 Current control loop with shunt measurement, PT1 filtering, PI control, duty-
cycle saturation and back-calculation anti-windup | 25

# List of Tables

# Chapter 1

# Introduction

Electric drive systems represent a core area of modern electrical engineering in which power electronics, control theory and embedded software converge to convert electrical energy into controlled mechanical motion. The design of such systems requires simultaneous consideration of multiple engineering disciplines, including semiconductor device physics, thermal management, feedback control, signal conditioning and real-time software architecture. This chapter introduces the motivation of the project, defines the problem scope and boundary conditions, and reviews the relevant technical background on DC motor drives and microcontroller-based motor control.

### 1.1 Motivation

The control of electric machines has been a central topic in electrical engineering since the introduction of thyristor-based DC drives in the 1960s [1]. Although brushless and AC drive technologies have largely replaced brushed DC motors in high-performance industrial applications, brushed DC motors remain widely used in cost-sensitive applications such as small electric vehicles, actuators and laboratory equipment. Their simple construction – a permanent-magnet stator and a wound armature with mechanical commutator – results in a straightforward relationship between applied terminal voltage and shaft speed, making them a suitable platform for studying fundamental drive concepts without the added complexity of field-oriented control or space-vector modulation required by AC machines. From a controltheoretic perspective, the brushed DC motor is described by a second-order linear system coupling the electrical circuit dynamics to the mechanical load dynamics. The electrical subsystem is governed by Kirchhoff’s voltage law applied to the armature circuit:

Va = Ra ia + La

dia
dt + Ke ω | (1.1)

where Va is the applied armature voltage, Ra and La are the armature resistance and inductance, ia is the armature current, Ke is the back-EMF constant and ω is the angular velocity. The mechanical subsystem is described by Newton’s second law for rotational motion:

J

dω
dt = Kt ia − B ω − TL | (1.2)

where J is the moment of inertia, Kt

is the torque constant, B is the viscous friction coefficient and TL is the load torque. These two coupled differential equations form the plant model that any speed or current controller must regulate. Pulse-width modulation provides an efficient mechanism to control the average voltage applied to the motor without the power dissipation penalties of linear regulation. In a PWM-based drive, a power transistor switches

ELT10140 - Team 1 | 24V/250W DC Motor Driver

the full supply voltage across the motor at a fixed frequency fPWM , and the average voltage is set by the duty cycle D:
V¯
a = D · Vsupply | (1.3)

When the PWM frequency is chosen well above the electrical time constant of the motor (τe = La/Ra), the resulting current ripple is small and the motor responds to the average voltage as if a continuous variable supply were applied [1]. The practical implementation of a PWM motor drive, however, involves considerably more than the control loop itself. The power stage must switch currents of several amperes with low conduction and switching losses. The gate driver must translate the microcontroller logic levels to the voltage levels required by the power transistors, often using a bootstrap technique for the high-side device. Current must be measured in real time for overcurrent protection and, optionally, for closed-loop current control. Finally, the complete system must be implemented on a printed circuit board with appropriate trace sizing, decoupling, thermal management and mechanical integration. This project addresses all of these aspects in the context of a 24 V, 250W brushed DC motor drive, providing practical experience in the full development cycle from specification through design, assembly, testing and documentation.

### 1.2 Problem Statement

The objective of this project is to design, build and verify an electronic control system for a Unite Motor MY1016 brushed DC motor rated at 24 V and 250W. The system must provide adjustable speed control through a user interface consisting of push-buttons and indicator LEDs, and must protect itself and the motor against overcurrent, motor blockage and other fault conditions without damage to any component. The main electronic subsystems – microcontroller (ATmega328P on an Arduino Nano module), half-bridge gate driver (IR2104), power MOSFETs (IRFZ44N), current sensing (shunt resistor with LM358 amplifier), voltage regulation (L7812 linear and LM2596 buck converter) and input protection (TVS diode and fuse) – are integrated on a single two-layer PCB. The motor and the 24 V laboratory power supply are connected as external components.The central engineering challenge is to ensure that all subsystems interact safely and reliably at the electrical, thermal and temporal interfaces. Specifically:

- The gate driver must provide sufficient gate-source voltage to fully enhance the power MOSFETs, including the high-side device whose source terminal floats at the switchingnode potential.
- The current measurement chain must have sufficient gain and bandwidth to detect an overcurrent condition within one PWM cycle, while rejecting switching noise.
- The PCB layout must carry the full motor current (≥ 13.7 A rated) with acceptable resistive losses and temperature rise, in accordance with IPC-2221.
- The firmware must implement a deterministic, non-blocking control loop with defined state transitions, soft-start, stall detection and fail-safe shutdown.

The scope of this work is limited to a laboratory prototype assembled on a wooden baseplate in an open-frame configuration. Direction reversal and regenerative braking are not required. The project follows the complete development cycle defined by the course: specification, design, procurement, assembly, test, documentation and presentation.

### 1.3 State of the Art

The control of brushed DC motors using power electronic converters has been a wellestablished practice in electrical engineering for several decades. Early DC drive systems relied on thyristor-based phase-controlled rectifiers to regulate the average voltage applied to the motor armature from an AC supply. With the widespread availability of power MOS-FETs and insulated-gate bipolar transistors in the 1980s and 1990s, chopper-based DC drives using pulse-width modulation became the dominant topology for battery-supplied and low-voltage DC motor applications. These PWM-based drives offer faster dynamic response, lower harmonic distortion and simpler control compared to phase-controlled rectifiers, and they remain the standard approach for brushed DC motor control in cost-sensitive applications such as small electric vehicles, industrial actuators and laboratory equipment [1, 2]. The power stage of a PWM motor drive is typically implemented as either a single low-side switch with a freewheeling diode, a half-bridge with two active switches, or a full H-bridge with four switches. The single-switch topology is the simplest but limits operation to a single quadrant, meaning only unidirectional speed control is possible. The half-bridge extends this by placing a high-side and a low-side MOSFET in a totem-pole configuration, where the midpoint (switching node) connects to one terminal of the motor. In synchronous rectification mode, the low-side MOSFET conducts during the off-time instead of a passive diode, which reduces conduction losses because the MOSFET channel resistance is typically much lower than the forward voltage drop of even a Schottky diode. The full H-bridge enables fourquadrant operation, including forward and reverse motoring as well as regenerative braking, but requires twice the number of switches and a more complex gate drive scheme. Since direction reversal is not required in many practical applications, the half-bridge remains a common and cost-effective choice [1]. A central challenge in half-bridge and H-bridge topologies is the gate drive of the high-side N-channel MOSFET, whose source terminal is connected to the switching node and therefore floats between ground and the supply voltage during PWM operation. To turn the high-side device fully on, a gate-source voltage of at least 10 V is required, referenced to this floating source potential. The bootstrap technique provides a simple and widely used solution to this problem. A small capacitor is charged through a diode from a fixed voltage rail during the interval when the low-side switch is on and the switching node is near ground. When the high-side switch turns on and the switching node rises, the charged capacitor floats with it and provides the gate-drive energy. Dedicated integrated gate driver ICs, such as the IR2104 from Infineon Technologies, combine the bootstrap supply management, level-shifting logic, internal dead-time generation and shutdown functionality in a single package. The application notes accompanying these devices provide detailed guidelines for bootstrap capacitor sizing, diode selection and layout recommendations [3, 4]. Current measurement is an essential function in any motor drive that must provide overcurrent protection or closed-loop current control. In low-voltage drives, the most common approach is to insert a low-value resistive shunt (typically 1–100 mΩ) in the motor current path and to amplify the resulting voltage using an operational amplifier or a dedicated current-sense amplifier. The amplified signal is then sampled by the microcontroller’s analog-to-digital converter. The main advantages of this approach are low cost, simplicity and direct proportionality between the shunt voltage and the instantaneous current. The main disadvantages are the additional power dissipation in the shunt (P = I

2R) and the
sensitivity to noise coupling from the switching node, which requires careful PCB layout with Kelvin-connected sense traces [5]. Alternative current sensing methods include Hall-effect current sensors, which provide galvanic isolation but at higher cost and typically lower bandwidth, and current-sense MOSFETs with integrated mirror elements, which are less common in discrete designs. The control and protection functions of a modern motor drive are typically implemented on a low-cost microcontroller. Devices such as the Atmel (now Microchip)

ATmega328P provide hardware timer/counter modules capable of generating PWM signals at frequencies of 20 kHz or higher with duty-cycle resolution of 10 bits or more, without continuous CPU intervention. The same device provides a successive-approximation ADC for current and voltage measurements, general-purpose I/O for user interface elements (buttons, LEDs, displays) and serial communication interfaces for diagnostics. The firmware implements a state machine that manages the operating modes of the drive, including start-up sequencing with current-limited soft-start ramps, steady-state speed control with discrete or continuous duty-cycle adjustment, fault detection (overcurrent, stall, over-temperature) and safe shutdown with defined output states. The non-blocking programming style, in which the main loop polls timing counters and sensor readings without using blocking delay functions, ensures that the protection logic remains responsive at all times [6]. Thermal management is a further consideration in the design of compact motor drives. The power dissipation in the MOSFETs, freewheeling diode and shunt resistor must be conducted away from the semiconductor junctions to the ambient environment through a thermal path that includes the component package, any thermal interface material, the PCB copper and, optionally, an external heatsink. The steady-state junction temperature is estimated using the thermal resistance chain from junction to ambient (Rθ,JA) and must remain below the maximum rating specified in the device datasheet. For surface-mount packages such as D2PAK, the thermal resistance is strongly influenced by the copper area on the PCB, making the layout a critical factor in the thermal design [7]. The present project applies these established techniques in a practical laboratory prototype. A half-bridge power stage with IRFZ44N MOSFETs is driven by an IR2104 gate driver with a BAS16J bootstrap diode. Current is sensed using a 10 mΩ shunt resistor amplified by an LM358 operational amplifier. The control, protection and user interface functions are implemented on an ATmega328P microcontroller (Arduino Nano module). All subsystems are integrated on a single two-layer PCB, while the motor and 24 V power supply are connected as external components.

# Chapter 2

# Circuit Design

This chapter presents the design of the motor driver circuit from the schematic level to the printed circuit board implementation. The circuit design is structured into three main parts. First, the electrical layout is described, including the power stage, driver electronics, voltage regulation, protection elements, and measurement interfaces. Based on this, a basic thermal analysis is performed to estimate the main sources of power dissipation and to assess the thermal feasibility of the selected components. Finally, the PCB design is evaluated with respect to component placement, routing of high-current paths, thermal management, and the integration of the circuit into the overall system. The complete circuit schematic is shown in Figure 2.1; a full-page version is included in Appendix A.2.

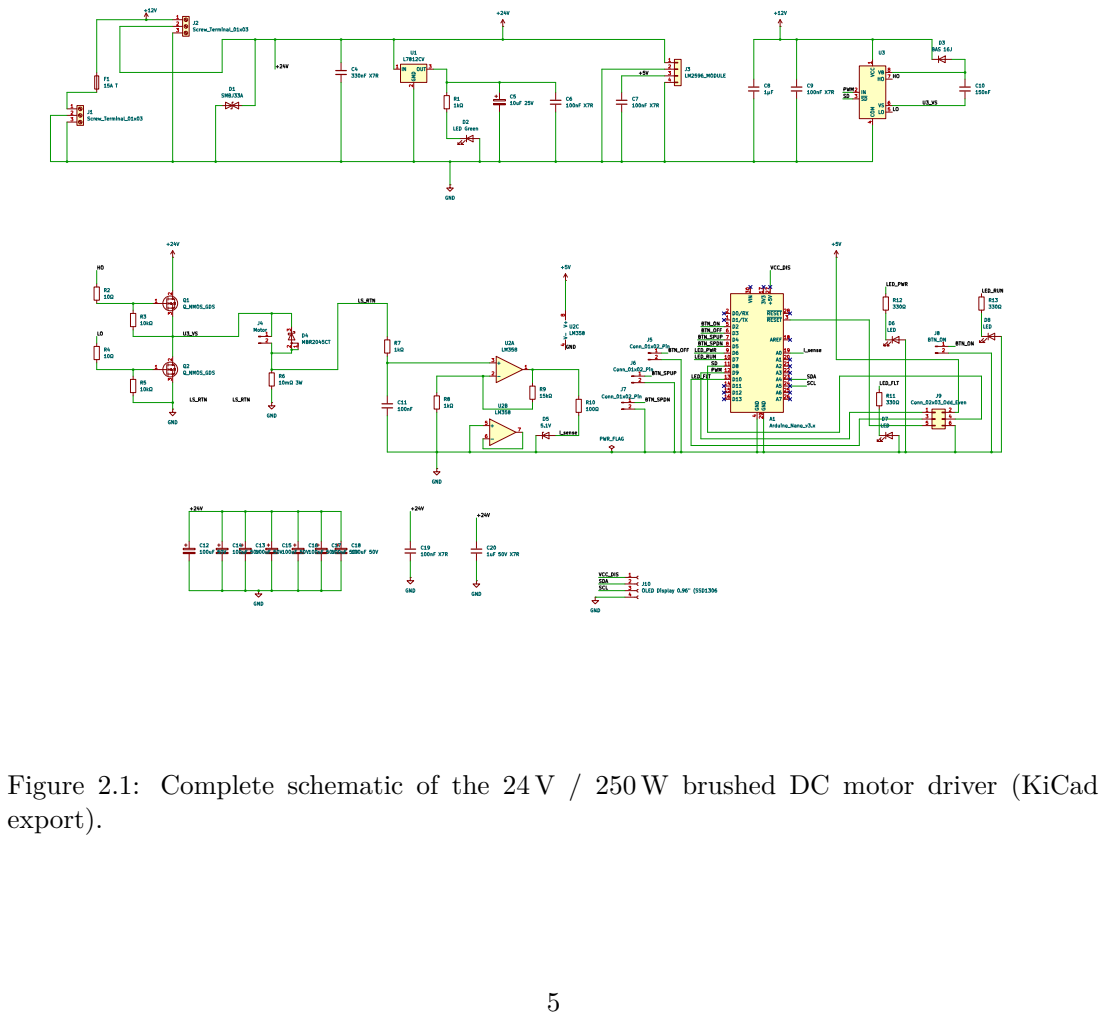
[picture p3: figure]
export).

Figure 2.1: Complete schematic of the 24 V / 250W brushed DC motor driver (KiCad

### 2.1 Electrical Layout

Compensation off Ripple Current and Ripple Voltage The input voltage of the motor driver is provided by a 24 V supply. Since the motor current is switched by the half-bridge using PWM, the DC link is subjected to pulsed current demands. These current pulses lead to voltage ripple on the supply rail due to the finite impedance of the supply path, the equivalent series resistance of the capacitors, and the parasitic inductances of the PCB traces and cables. In addition, the buck converter used for the auxiliary electronics introduces high-frequency switching components. For this reason, the 24 V rail is supported by a combination of electrolytic bulk capacitors and ceramic decoupling capacitors. The electrolytic capacitors mainly act as local energy storage for the power stage [1, 2]. In the present design, eight electrolytic capacitors are connected in parallel. Each capacitor has an equivalent series resistance of approximately

ESRelko = 300 mΩ = 0.3 Ω. | (2.1)

Assuming an ideal current distribution between the capacitors, the equivalent series resistance of the capacitor bank is given by

ESReq =

ESRelko
n

=

0.3 Ω
8
= 0.0375 Ω. | (2.2)

Thus, the parallel connection reduces the effective equivalent series resistance to

ESReq = 37.5 mΩ. | (2.3)

The total capacitance of the DC-link capacitor bank is calculated by

Ceq = n · Celko. | (2.4)

For eight capacitors with a capacitance of 100 µF each, the resulting total capacitance is

Ceq = 8 · 100 µF = 800 µF. | (2.5)

The voltage ripple at the DC link consists of an ESR-related component and a capacitive component. The ESR-related voltage ripple can be approximated by [2]

∆VESR ≈ Iripple,rms · ESReq. | (2.6)

For a basic estimation, the RMS ripple current of the capacitor bank can be approximated by
Iripple,rms ≈ Iloadq
D(1 − D). | (2.7)

The maximum value occurs at a duty cycle of approximately D = 0.5. With a nominal motor current of Iload = 10.24 A, this gives

Iripple,rms ≈ 10.24 Aq
0.5(1 − 0.5) = 5.12 A. | (2.8)

Using this value, the ESR-related voltage ripple is estimated as

∆VESR ≈ 5.12 A · 0.0375 Ω = 0.192 V. | (2.9)

The corresponding power dissipation in the complete capacitor bank is given by

Ploss = I

2
ripple,rms · ESReq. | (2.10)

This results in
Ploss = (5.12 A)²
- 0.0375 Ω ≈ 0.98W. | (2.11)

Assuming ideal current sharing, the loss per electrolytic capacitor is

Ploss,elko =

0.98W
8
≈ 0.12W. | (2.12)

The capacitive part of the voltage ripple can be estimated by [1]

∆VC ≈

Iload · D(1 − D)

Ceq · fPWM

. | (2.13)

With Iload = 10.24 A, D = 0.5, Ceq = 800 µF, and fPWM = 20 kHz, this gives

∆VC ≈

10.24 A · 0.5(1 − 0.5)
800 µF · 20 kHz
≈ 0.16 V. | (2.14)

The estimation shows that both the ESR-related voltage ripple and the capacitive voltage ripple contribute significantly to the total voltage ripple of the DC link. The parallel connection of multiple electrolytic capacitors is therefore useful not only to increase the available capacitance, but also to reduce the effective equivalent series resistance and to distribute the ripple-current-related losses over several components. The ceramic capacitors complement the electrolytic capacitors at higher frequencies. Due to their lower equivalent series inductance and lower impedance at high frequencies, they provide a local path for fast switching current components. Thus, the electrolytic capacitors stabilize the 24 V bus against larger low-frequency current variations, while the ceramic capacitors suppress high-frequency voltage transients generated by the half-bridge and the buck converter.

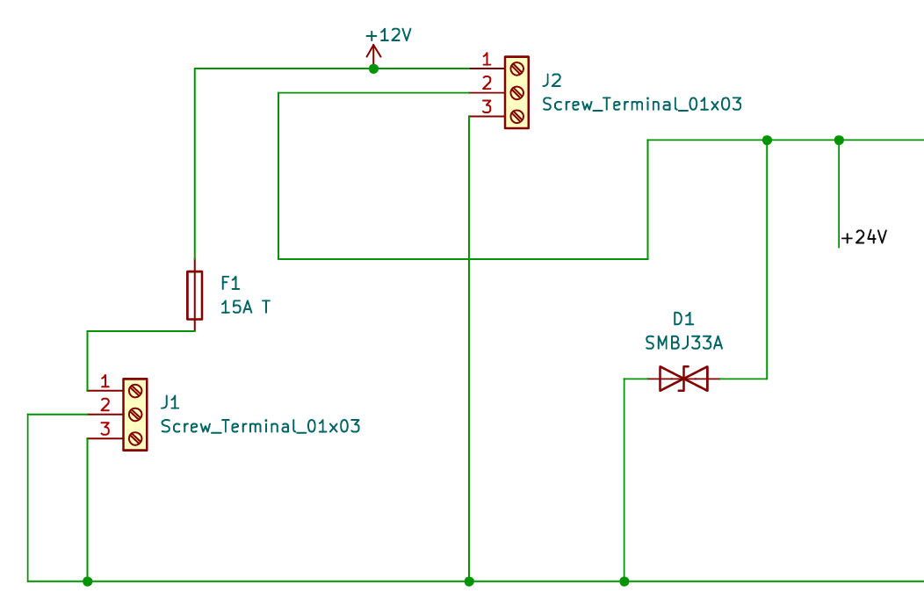
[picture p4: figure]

Figure 2.2: Input protection section of the schematic: screw terminals J1 and J2, 15 A fuse F1, and TVS diode D1 (SMBJ33A).

Linear Voltage Regulator The gate driver IC and the bootstrap circuit require a supply voltage in the range of 10 to 20 V. The IR2104 gate driver enforces this constraint through an internal under-voltage lockout with a positive-going threshold of VCCUV+ = 8.9 V (typical) and a negative-going threshold of VCCUV− = 8.2 V (typical), as specified in the IR2104 datasheet [3]. Since the 5 V rail generated by the buck converter module is below this threshold, a separate 12 V supply is required. This supply is provided by the STMicroelectronics L7812CV linear voltage regulator (U1), which converts the 24 V bus to a regulated 12 V output. A 330 nF X7R ceramic capacitor (C4) is placed directly at the input of U1. This capacitor serves as both the high-frequency input bypass for the regulator and a local charge reservoir for the switching transients coupled from the power stage. The L7812 datasheet (STMicroelectronics L7800 series, Application circuits, Fig. 4) recommends a minimum input capacitance of Cin ≥ 0.33 µF, which is satisfied by C4. The output of U1 feeds a rail designated Net-(U1-OUT) in the netlist. Two capacitors are placed on this rail: a 10 µF / 25 V electrolytic capacitor (C5) and a 100 nF X7R ceramic capacitor (C6). The electrolytic capacitor provides bulk energy storage and improves the transient response of the regulator under sudden load steps, for example when the IR2104 charges both MOSFET gates simultaneously. The ceramic capacitor provides a low-impedance path at higher frequencies. A 25 V voltage rating for C5 provides a derating margin of more than 2× above the 12 V operating voltage. The L7812 output also supplies a green LED (D2) through a 1 kΩ series resistor (R1), which serves as a visual power-on indicator. The LED forward current is approximately

ILED =

Vout − VF
R1

=

12 V − 2 V
1 kΩ | = 10 mA. | (2.15)

The total current demand on the 12 V rail is low. The IR2104 quiescent supply current is IQCC = 150 µA (typical) [3], and the average gate-drive current per MOSFET at 20 kHz is

Igate,avg = Qg · fPWM = 63 nC · 20 kHz = 1.26 mA. | (2.16)

Including the LED current, the total 12 V load is estimated at approximately 25 mA. The worst-case power dissipation in U1 is therefore

PL7812 = (Vin − Vout) · Iout = (24 V − 12 V) · 25 mA = 0.30W. | (2.17)

With the TO-220 package thermal resistance of Rθ,JA = 50 KW⁻¹
| | (STMicroelectronics
L7800 datasheet, Thermal data), the estimated junction temperature rise above ambient is ∆T = 0.30W·50 KW⁻¹ = 15 K, resulting in a junction temperature of approximately 40 ◦C. This is well within the maximum junction temperature of 150 ◦C, and no external heatsink is required.

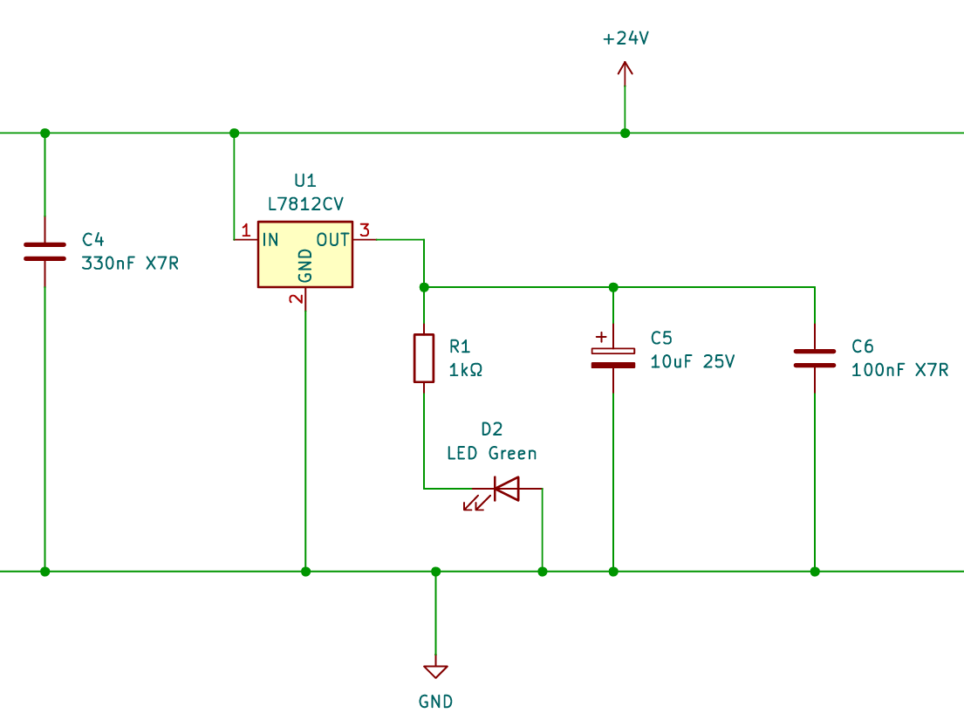
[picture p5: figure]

Figure 2.3: Linear voltage regulator section: L7812CV (U1) with input capacitor C4 (330 nF), output capacitors C5 (10 µF) and C6 (100 nF), power-on indicator LED D2 with series resistor R1 (1 kΩ).

Gate Driver and Bootstrap Circuit The IR2104 (U3) is a half-bridge gate driver from Infineon Technologies. It accepts a logic-level PWM input signal on pin 2 (IN) and generates non-overlapping complementary gate-drive outputs for the high-side MOSFET Q1 (via HO, pin 7) and the low-side MOSFET Q2 (via LO, pin 5). The device generates an internally fixed dead time of tDT = 520 ns (typical, range 400 to 650 ns), which prevents simultaneous conduction of both MOSFETs [3]. An active-low shutdown input (SD, pin 3) allows the microcontroller to disable both outputs and force the gate driver into a safe state. The input logic thresholds are VIH ≥ 3.0 V and VIL ≤ 0.8 V [3]. Since the ATmega328P GPIO outputs swing between 0 V and 5 V [6], the logic levels are directly compatible with the IR2104 input thresholds without a level shifter. The VCC pin (pin 1) of U3 is connected to the +12 V rail. Two decoupling capacitors are placed directly on this rail at U3: a 1 µF capacitor (C8) and a 100 nF X7R ceramic capacitor (C9). These capacitors provide a local charge reservoir and a low-impedance path for the pulsed current drawn by the gate driver during switching events. The COM pin (pin 4) is connected to circuit ground. Each MOSFET gate is driven through a 10 Ω series resistor (R2 for Q1, R4 for Q2). These resistors control the gate voltage slew rate and damp parasitic oscillations in the gate loop [4]. With a 12 V gate drive supply, the peak gate current through each resistor is limited to

Igate,peak =

VCC
Rg

=

12 V
10 Ω = 1.2 A. | (2.18)

In practice, the peak current is limited by the output impedance of the IR2104 driver stage, which can source 210 mA and sink 360 mA [3]. The 10 Ω resistor therefore primarily serves as a damping element rather than a current limiter. A 10 kΩ pull-down resistor is placed between gate and source of each MOSFET (R3 for Q1, R5 for Q2) to ensure a defined low gate voltage during power-up, before the gate driver output stage is active. Driving the gate of the high-side N-channel MOSFET Q1 requires a gate-source voltage referenced to the source of Q1, which is the switching node. During PWM operation, the switching node floats between 0 V and approximately 24 V. A gate driver supply referenced to the fixed ground rail cannot directly provide this floating drive voltage. The bootstrap technique solves this problem by using a capacitor to store a charge referenced to the switching node [4]. The bootstrap diode D3 (BAS16J, SOD-323F package) and the bootstrap capacitor C10 (1 µF) form the bootstrap network. During the interval in which the low-side MOSFET Q2 is conducting, the switching node VS is pulled close to ground, and the bootstrap capacitor C10 charges through D3 from the 12 V supply to approximately

VC10 ≈ VVCC − VF,D3 ≈ 12 V − 0.7 V = 11.3 V. | (2.19)

When Q2 turns off and Q1 must be switched on, the VS node rises toward the 24 V bus. The bootstrap capacitor floats with the switching node, so the VB pin of the gate driver rises to VS + VC10, which is above the supply voltage. The IR2104 uses VB as its high-side supply and drives HO between VB and VS, providing the required gate-source voltage to turn Q1 fully on [3, 4]. During this interval, D3 is reverse-biased and prevents C10 from discharging back into the 12 V supply. The BAS16J was selected for its fast switching characteristic (trr ≤ 4 ns), which minimises charge leakage from the bootstrap capacitor during high-frequency switching. Its reverse voltage rating of 75 V provides adequate margin. The charge removed from C10 per switching cycle is dominated by the total gate charge of Q1. With Qg = 63 nC and the IR2104 bootstrap quiescent current IQBS = 55 µA (maximum) [3], the total charge drawn per cycle at the worst-case maximum on-time of ton = 50 µs is

Qtotal = Qg + IQBS · ton = 63 nC + 55 µA · 50 µs = 65.75 nC. | (2.20)

The resulting voltage droop on the bootstrap capacitor per cycle is

∆VC10 =

Qtotal

C10

=

65.75 nC
1 µF
= 0.066 V. | (2.21)

This droop of approximately 66 mV is small compared to the 11.3 V bootstrap voltage, confirming that the 1 µF capacitor provides sufficient energy storage for reliable high-side gate drive at 20 kHz, consistent with the bootstrap design methodology outlined in [4]. The freewheel diode D4 (MBR2045CT) provides a current path for the motor inductive current during the dead time when both MOSFETs are off. The MBR2045CT is a dual commoncathode Schottky rectifier rated for 20 A average forward current and 45 V reverse voltage (Vishay document 87591). Its low forward voltage drop of approximately 0.84 V minimises the conduction loss during the freewheeling interval compared to the body diode of the MOSFET [1].

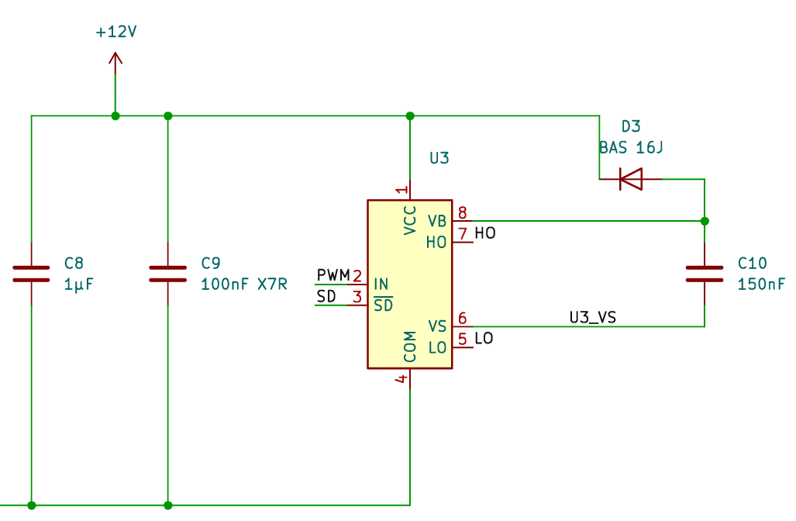
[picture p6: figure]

Figure 2.4: Gate driver and bootstrap circuit: IR2104 (U3) with VCC decoupling capacitors C8 (1 µF) and C9 (100 nF), bootstrap diode D3 (BAS 16J) and bootstrap capacitor C10.

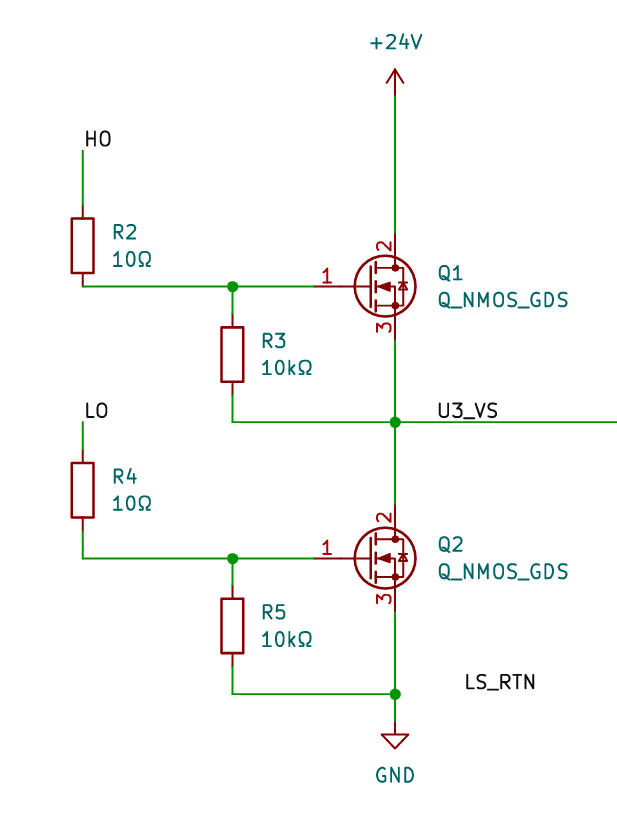
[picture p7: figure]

Figure 2.5: Half-bridge power stage: high-side MOSFET Q1 and low-side MOSFET Q2 (IRFZ44N) with gate resistors R2, R4 (10 Ω) and gate pull-down resistors R3, R5 (10 kΩ).

Buck Converter The 5 V supply for the Arduino Nano (A1), the LM358 current-sense amplifier (U2), the indicator LEDs (D6, D7, D8) and the button interface connectors is generated by a pre-assembled LM2596-based buck converter module connected at J3. The module input (J3 pin 1) is connected to the +24 V bus, and the output (J3 pin 3) provides the regulated +5 V rail. This connection was verified in the PCB netlist, which assigns J3 pin 1 to the +24 V net and J3 pin 3 to the +5 V net. The pre-assembled module integrates the LM2596 switching regulator IC, inductor, Schottky catch diode and feedback network, avoiding the layout-critical aspects of a discrete switching regulator design [2]. A 100 nF X7R ceramic capacitor (C7) is placed on the +5 V rail on the PCB. This capacitor provides additional local high-frequency decoupling at the PCB level and supplements the output capacitors already present on the module itself. The +5 V rail connects directly to the power supply pins of the Arduino Nano (A1), the supply pin of the LM358 operational amplifier (U2, pin 8), the OLED display connector (J10) and the indicator LEDs.

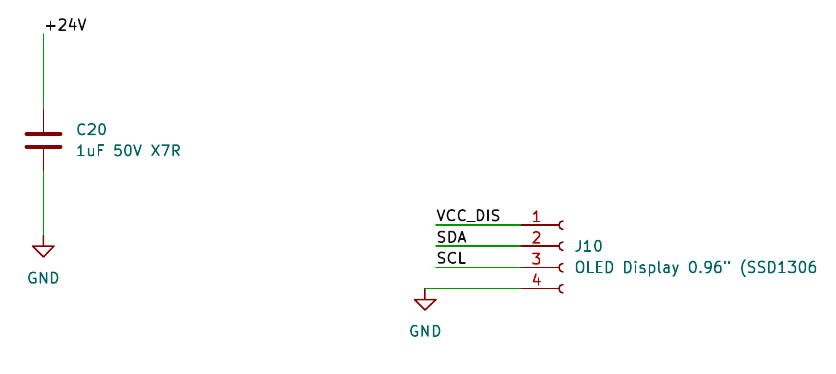
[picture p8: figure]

Figure 2.6: Buck converter module and OLED display connector: LM2596 module at J3 (24 V → 5 V), local decoupling capacitor C20 (1 µF) and OLED display connector J10 (SSD1306, I²C).

The motor current is measured using a low-side shunt resistor and a non-inverting amplifier, following the standard current-sensing approach for motor drive applications [5]. A 10 mΩ / 3W shunt resistor (R6) is placed in the LS_RTN net between the source of the low-side MOSFET Q2 and the ground return. The voltage developed across the shunt is proportional to the instantaneous motor current. At the rated motor current, this voltage is

Vshunt = Imotor · Rshunt = 13.7 A · 10 mΩ = 0.137 V. | (2.22)

This voltage is too small to be read directly by the microcontroller ADC with useful resolution. It is therefore amplified by the LM358 dual operational amplifier (U2). Channel A of the LM358 is configured as a non-inverting amplifier with the shunt voltage applied to the non-inverting input (pin 3) through a 1 kΩ input resistor (R7) and a 100 nF input filter capacitor (C11). The gain is set by the feedback network consisting of R8 = 1 kΩ (inverting input to ground) and R9 = 15 kΩ (feedback from output to inverting input):

G = 1 +

R9
R8

= 1 +

15 kΩ
1 kΩ = 16. | (2.23)

At the rated motor current, the amplifier output voltage is

Vout,sense = G · Vshunt = 16 · 0.137 V = 2.19 V. | (2.24)

The amplifier output is connected to the Arduino ADC input A0 through a 100 Ω series resistor (R10), with a 5.1 V Zener diode (D5) providing overvoltage protection at the ADC input. The ATmega328P 10-bit ADC with VREF = 5.0 V [6] produces the following count at rated current:

ADCrated =

Vout,sense

VREF

- 1023 =

2.19 V
5.0 V
- 1023 ≈ 448. | (2.25)

At the overcurrent protection threshold of 20 A, the corresponding values are

Vout,20A = 16 · (20 A · 10 mΩ) = 3.20 V, | (2.26)

ADC20A =

3.20 V
5.0 V
- 1023 ≈ 655. | (2.27)

This output voltage of 3.20 V is within the linear output range of the LM358, which can swing to approximately VCC − 1.5 V = 3.5 V on the positive side (TI datasheet SNOSBT3). The LM358 input offset voltage of up to 7 mV is amplified to 16 × 7 mV = 112 mV at the output, corresponding to a measurement error of approximately 0.7 A or 3.5 % of the 20 A threshold. This error is removed by a zero-offset calibration performed in firmware at power-on, a technique commonly recommended for shunt-based current sensing [5]. Channel B of the LM358 is unused; its inverting input (pin 6) is connected to its output (pin 7) to form a unity-gain buffer and prevent oscillation on the floating input.

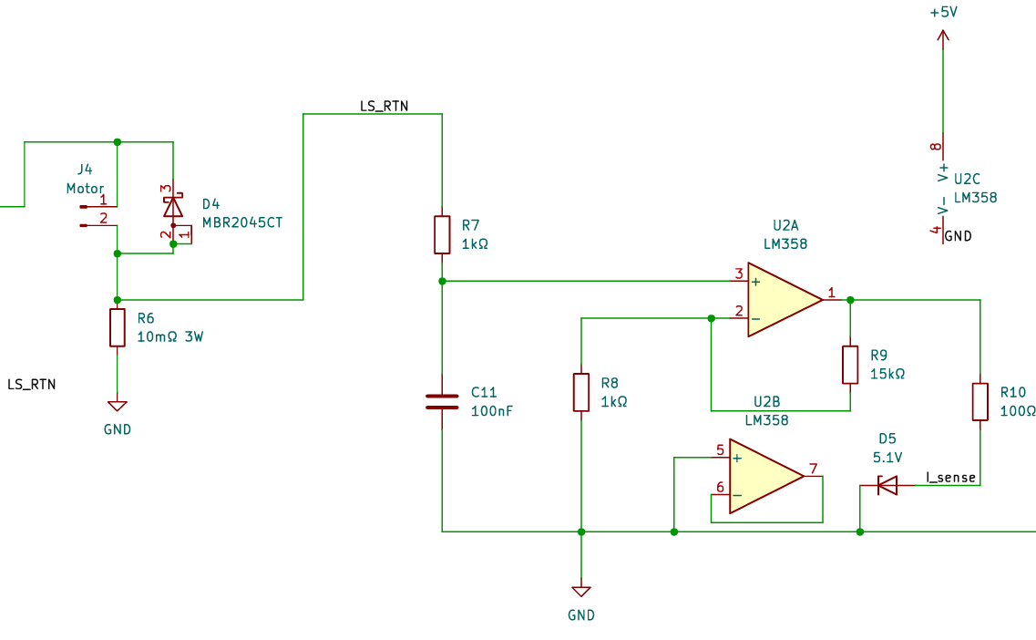
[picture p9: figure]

Figure 2.7: Current sensing circuit: motor output connector J4 with freewheeling diode D4 (MBR2045CT), low-side shunt resistor R6 (10 mΩ, 3W), LM358 non-inverting amplifier (U2A, gain = 16) with input filter C11, feedback resistors R8 and R9, ADC protection resistor R10 (100 Ω) and Zener diode D5 (5.1 V). Channel B (U2B) is configured as a unity-gain buffer.

Three indicator LEDs are connected to GPIO outputs of the Arduino Nano through 330 Ω current-limiting resistors: R12 with D6 (power), R11 with D7 (fault), and R13 with D8 (run). The LED forward current at a typical forward voltage of 2 V is

ILED =

VCC − VF
R

=

5.0 V − 2.0 V
330 Ω | = 9.1 mA. | (2.28)

This is within the absolute maximum GPIO current of 40 mA per pin specified in the ATmega328P datasheet [6]. Four two-pin connectors (J5, J6, J7, J8) provide the push-button interface for OFF, Speed-Up, Speed-Down and ON functions. Each button connects the corresponding GPIO pin to ground when pressed; the ATmega328P internal pull-up resistors hold the pins high in the unpressed state [6]. An optional 0.96-inch OLED display (SSD1306) is connected via the I²C interface (SDA, SCL) through connector J10.

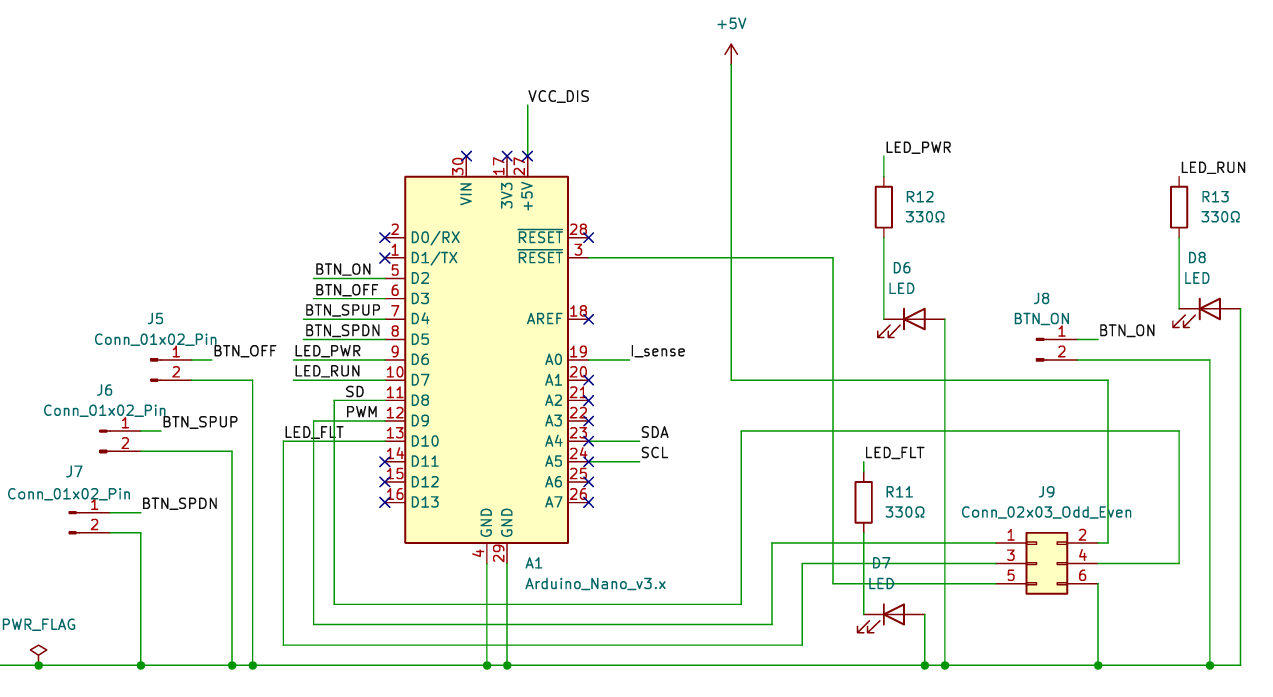
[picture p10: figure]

Figure 2.8: Control board and user interface: Arduino Nano (A1, ATmega328P) with button connectors J5–J8 (OFF, Speed-Up, Speed-Down, ON), ISP header J9, status LEDs D6 (power), D7 (fault) and D8 (run) with 330 Ω current-limiting resistors R11, R12 and R13.

### 2.2 Basic Thermal Analysis

The thermal analysis was performed in order to identify the components of the circuit that are most likely to limit the continuous operating capability of the motor driver. Since the circuit contains both high-current switching elements and low-power control electronics, not all components are equally relevant from a thermal point of view. The main focus was therefore placed on the components that either conduct the motor current directly or dissipate switching-related losses. These components are the high-side MOSFET Q1, the low-side MOSFET Q2, the freewheel diode D2, the current sense shunt R5 and the IR2104 half-bridge gate driver. The MOSFETs were considered critical because they carry the motor current during PWM operation and additionally dissipate switching losses during each commutation event [1]. The freewheel diode was included because the selected operating mode assumes diode freewheeling during the off-time of the PWM signal, which can lead to significant conduction losses. The shunt resistor was included because its losses scale quadratically with the motor current. The gate driver was also considered, although its losses are comparatively small, because it supplies the MOSFET gate charge at the PWM frequency. Other components, such as the bootstrap diode, bootstrap capacitor, operational amplifier and microcontroller, were not treated as dominant heat sources in this first-order estimate, because their expected dissipation is small compared to the high-current power stage. The analysis is based on a simplified but transparent loss model. For the nominal operating point, a supply voltage of Vsupply = 24 V, a motor current of Imotor = 10 A, a PWM frequency of fPWM = 20, kHz), a duty cycle of D = 0.5 and an ambient temperature of Tamb = 25,

- C were assumed. The conduction losses of the MOSFETs were calculated from the RMS current approximation during the corresponding duty interval. For a MOSFET with drain-source on-resistance RDS,on, the conduction loss is given by [1, 2]

Pcond = I

2DRDS,on. | (2.29)

The switching loss was estimated by assuming a linear overlap of voltage and current during the rise and fall transitions. With the drain-source voltage VDS, drain current ID, rise time tr, fall time tf and PWM frequency fPWM, the switching loss is approximated as [1, 2]

Psw =

1
VDSID (tr + tf) fPWM. | (2.30)

The total MOSFET loss is then obtained by adding conduction and switching losses:

PMOSFET = Pcond + Psw. | (2.31)

For the gate driver, the loss contribution caused by charging and discharging the MOSFET gates was estimated from the total gate charge. With the gate charge Qg, gate voltage VGS and PWM frequency fPWM, the corresponding gate-drive loss is [4]

Pgate = QgVGSfPWM. | (2.32)

This loss is mainly dissipated in the gate driver and the gate resistance and is therefore not fully assigned to the MOSFET junction itself. In the diode freewheeling case, the freewheel diode was modeled using a linearized conduction loss relation. The average and RMS diode currents during the off-time are

IF,av = Imotor (1 − D), | (2.33)

IF,rms = Imotor

√
1 − D. | (2.34)

The diode loss was then approximated by [2]

Pdiode = aIF,av + bI²
F,rms, | (2.35)

where (a) and (b) are the parameters of the simplified diode loss model. For the current sense resistor, the dissipated power is determined by the ohmic loss

Pshunt = I

2Rshunt. | (2.36)

After calculating the individual power losses, the steady-state temperature of each component was estimated using a lumped thermal resistance model. The temperature rise above ambient is proportional to the dissipated power and the thermal resistance from the component to the ambient environment:
∆T = PlossRth. | (2.37)

The corresponding steady-state temperature is

Tss = Tamb + PlossRth. | (2.38)

This model is suitable for an initial design estimate, but it does not replace detailed PCBlevel thermal simulation or measurements on the final hardware. In particular, the assumed thermal resistances depend strongly on the package, copper area, airflow and heat spreading through the PCB [7]. The resulting steady-state temperatures are shown in Figure 2.9. The highest estimated temperature occurs at the high-side MOSFET Q1, which reaches approximately 108,

- C under the nominal assumptions. This is mainly caused by the combination of conduction losses and switching losses. The freewheel diode D2 reaches approximately 95,
- C, which makes it the second most critical component in this estimate. In contrast, the low-side MOSFET Q2 remains much cooler in the selected diode-freewheeling mode, because it only contributes switching losses and does not conduct during the off-time. The shunt resistor reaches approximately 60,
- C, while the gate driver remains close to ambient temperature due to its small gate-drive loss. To estimate the transient heating behavior, each component was additionally modeled as a first-order thermal system with thermal resistance Rth and thermal capacitance Cth. The corresponding thermal time constant is
τ = RthCth. | (2.39)

For a constant power loss, the component temperature over time is described by

T(t) = Tss + (T0 − Tss) e

−t/τ
, | (2.40)

Q1 | Q2 | D2 | U1 | R5

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
Component

Temperature in

◦C

Steady-state temperature

Figure 2.9: Estimated steady-state component temperatures for the nominal operating point.

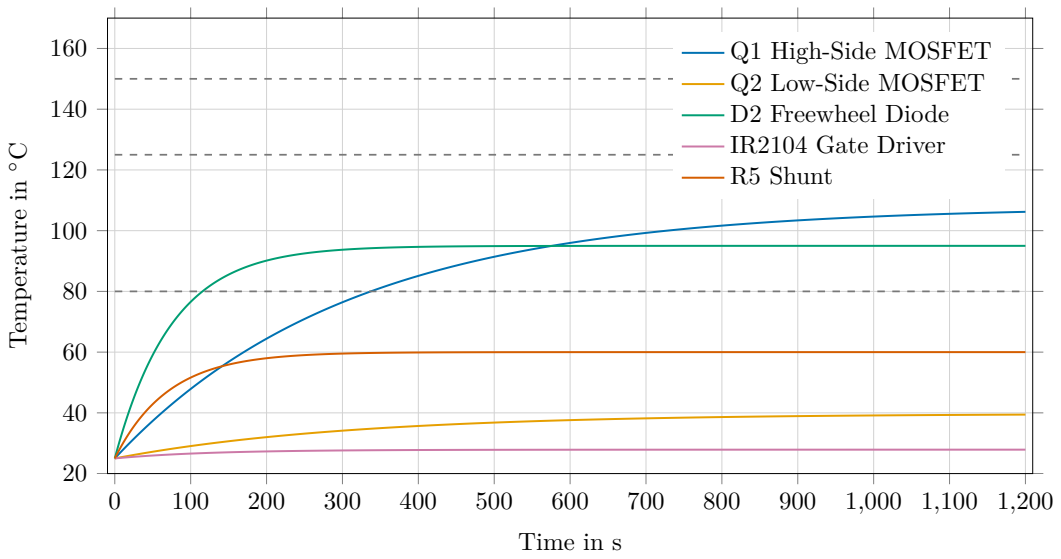
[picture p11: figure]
Time in s; Temperature in; Q1 High-Side MOSFET; Q2 Low-Side; MOSFET; D2 Freewheel Diode; IR2104 Gate; Driver; R5 Shunt

Figure 2.10: Transient temperature response using independent first-order thermal models.

where T0 is the initial component temperature. This equation describes the exponential approach from the initial temperature to the steady-state temperature. Figure 2.10 shows the transient response of the investigated components. The curves indicate that the high-side MOSFET and the freewheel diode are not only the hottest components in steady state, but also the most relevant components during longer operation. The result also shows that the temperature rise is not instantaneous, because the assumed thermal capacitances introduce a thermal delay. Nevertheless, for continuous operation the steady-state values remain the decisive design criterion. In order to evaluate the sensitivity of the design with respect to the motor current, a current sweep was carried out. Since several loss mechanisms depend quadratically on current, especially MOSFET conduction losses and shunt losses, the motor current has a strong influence on the thermal behavior.

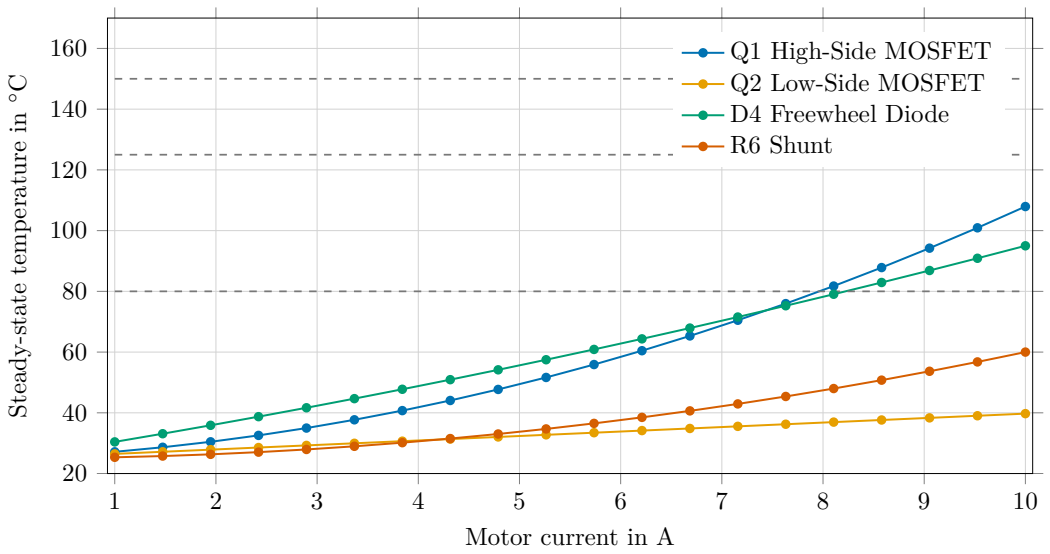
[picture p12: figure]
Motor current in A; Steady-state temperature in; Q1 High-Side MOSFET Q2 Low-Side MOSFET D4 Freewheel Diode R6 Shunt

Figure 2.11: Influence of the motor current on the estimated steady-state temperature of the main power components.

As shown in Figure 2.11, the temperatures of the high-side MOSFET, freewheel diode and shunt resistor increase significantly with current. This confirms that the motor current is the dominant operating parameter for the thermal design. The freewheel diode and the high-side MOSFET become especially critical near the nominal current of 10, A, while the low-side MOSFET remains comparatively uncritical in the diode-freewheeling configuration. The PWM frequency was also varied in order to evaluate the influence of switching losses. In the simplified switching loss model, the switching loss is directly proportional to the PWM frequency [1]. Therefore, increasing the PWM frequency reduces current ripple and acoustic noise, but increases the thermal stress on the switching devices.

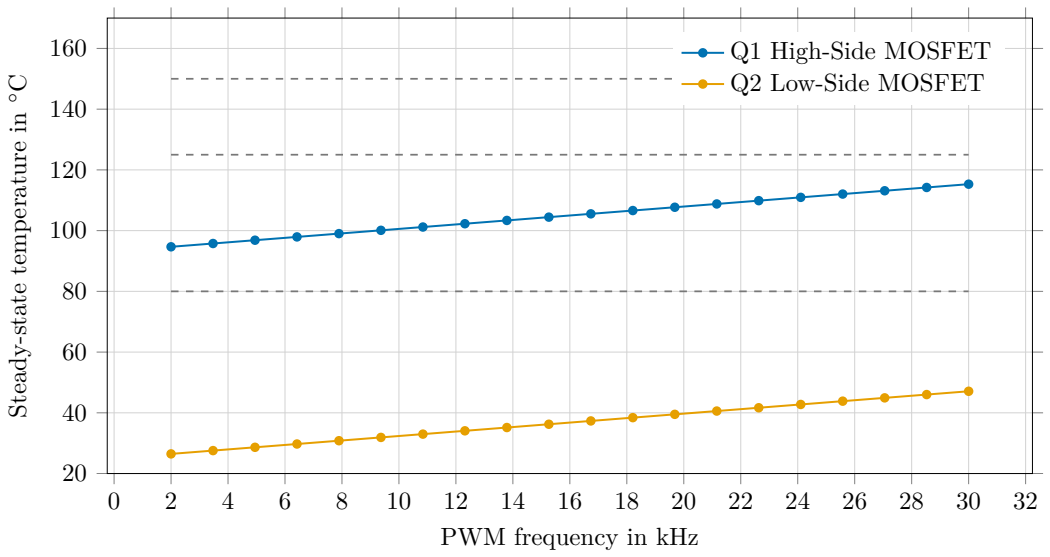
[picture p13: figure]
PWM frequency in kHz; Steady-state temperature in; Q1 High-Side MOSFET Q2 Low-Side MOSFET

Figure 2.12: Influence of the PWM frequency on the estimated MOSFET temperature.

Figure 2.12 shows that the estimated MOSFET temperatures increase approximately linearly with the PWM frequency. The effect is more visible for Q2 because, in the selected model, Q2 only dissipates switching losses. For Q1, the switching-related increase is added to the already present conduction loss. This confirms that the selected PWM frequency should not be increased without considering the resulting thermal penalty. A further parameter sweep was performed for the duty cycle. The duty cycle changes the distribution of conduction time between the high-side MOSFET and the freewheel path. In the diode-freewheeling mode, a higher duty cycle increases the high-side MOSFET conduction interval, while reducing the diode freewheeling interval.

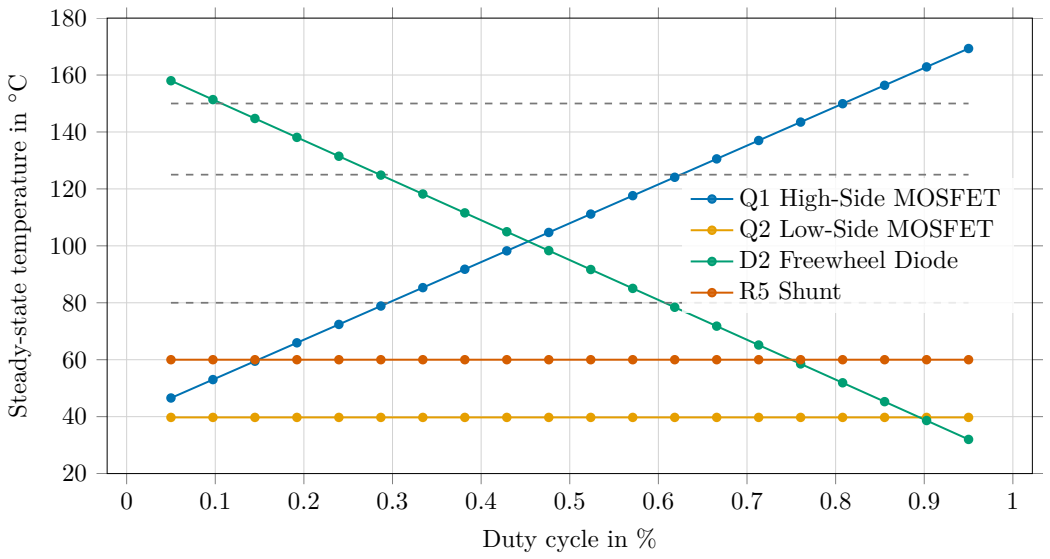
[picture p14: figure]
Duty cycle in %; Steady-state temperature in; Q1 High-Side MOSFET Q2 Low-Side MOSFET D2 Freewheel Diode R5 Shunt

Figure 2.13: Influence of the duty cycle on the estimated steady-state temperature of the main power components.

The duty-cycle sweep in Figure 2.13 shows this thermal load shift clearly. At low duty cycles, the freewheel diode dissipates a large fraction of the power because the off-time is long. At high duty cycles, the diode loss decreases, while the high-side MOSFET temperature increases due to the longer conduction interval. The shunt temperature remains constant in this sweep because the motor current was kept constant. Because the MOSFET on-resistance increases with junction temperature, an additional feedback calculation was performed for Q1. The temperature dependence of the on-resistance was approximated by [2]

RDS,on(T) = RDS,on,25 [1 + α (T − 25 ◦C)] . | (2.41)

This feedback increases the calculated Q1 loss because a higher temperature increases RDS,on, which further increases the conduction loss. In the nominal calculation without this feedback, Q1 reaches approximately 108,

- C. With the temperature-dependent on-resistance included, the estimated Q1 temperature increases to approximately 151,
- C. This result shows that the simple constant RDS,on calculation can underestimate the MOSFET temperature and that cooling measures or a MOSFET with lower on-resistance should be considered for continuous operation. Finally, a simplified PCB-coupled thermal network was evaluated to represent heat spreading through the circuit board [7]. In this model, each component is connected to a common PCB thermal node by a component-to-PCB thermal resistance. The PCB node is then connected to the ambient environment by a PCB-to-ambient thermal resistance. For each component (i), the thermal differential equation is

Ci

dTi
dt

= Pi −

Ti − TPCB

Ri,PCB

. | (2.42)

The PCB temperature is described by

CPCB

dTPCB
dt

=

X

i

Ti − TPCB

Ri,PCB

−

TPCB − Tamb

RPCB,amb

. | (2.43)
0 | 100 | 200 | 300 | 400 | 500 | 600 | 700 | 800 | 900 1,000 1,100 1,200

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
Time in s

Temperature in

- C

Q1 High-Side MOSFET
Q2 Low-Side MOSFET
D2 Freewheel Diode
IR2104 Gate Driver
R5 Shunt
PCB

Figure 2.14: Transient thermal response of the simplified PCB-coupled thermal network.

The coupled thermal network in Figure 2.14 shows that the PCB temperature rises together with the component temperatures. This model is still a simplified approximation, but it is more realistic than treating all components as thermally independent. The result indicates that the board itself becomes a relevant thermal path and that sufficient copper area, thermal vias, component spacing and possible heatsinking should be considered in the PCB design [7]. Overall, the basic thermal analysis identifies Q1 and D2 as the most critical components under the assumed diode-freewheeling operating point. The shunt resistor is relevant but remains within an acceptable range in the nominal estimate, while the gate driver is thermally uncritical. The analysis therefore supports the need for careful MOSFET selection, diode cooling, and a PCB layout with adequate heat spreading capability.

### 2.3 PCB Design

The printed circuit board was designed as a two-layer PCB for the integration of the motor power stage, the voltage supply, the gate driver circuit, the current measurement and the microcontroller interface. The layout was created with the objective of separating the high-current power path from the low-power control and signal circuitry as far as possible, while still keeping the switching loop of the half-bridge compact [4]. Figure 2.15 shows the PCB layout with a board size of 130 mm×93 mm. The input supply and bulk capacitors are placed along the upper edge of the PCB. From there, the 24 V power rail is routed with wide copper areas towards the fuse, the half-bridge stage and the motor output. The control electronics, including the Arduino Nano interface and the low-power signal routing, are located mainly in the lower and central part of the board. This placement reduces unnecessary overlap between high-current traces and sensitive control signals. The layout was designed according to the EMA-Lab PCB design rules for the DC motor controller project. The board outline was defined in metric units and with full millimeter dimensions. For a two-layer PCB without special mechanical requirements, the specified board thickness is 1.55 mm. The manufacturer

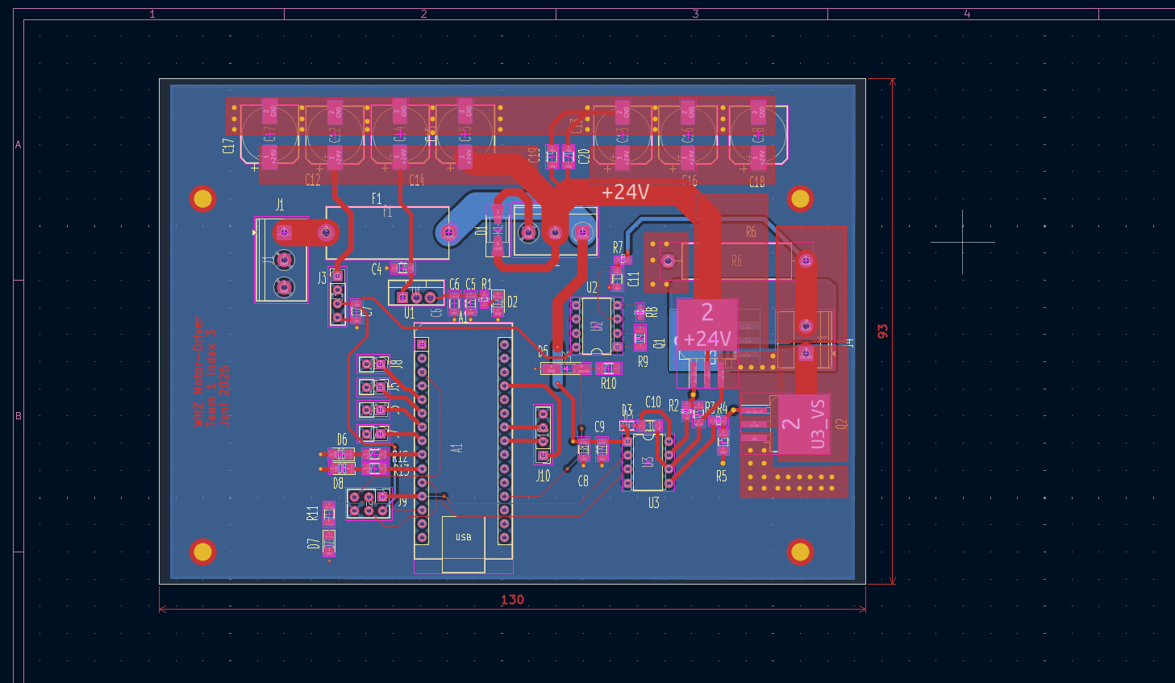
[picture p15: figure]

Figure 2.15: PCB layout of the DC motor driver showing the arrangement of the power stage, input capacitors and control electronics.

standard copper thickness is 35 µm after galvanic plating, while a 70 µm copper option may be used if required by the current carrying capability. The minimum trace width and minimum trace spacing specified by the project design rules are both 0.2 mm. Vias require a minimum finished hole diameter of 0.3 mm and a minimum annular ring of 0.25 mm. For the solder mask, a minimum solder mask web width of 0.1 mm and a solder mask clearance of 0.1 mm were considered. The minimum electrical clearance was evaluated according to EN 60664-1:2003. For the voltage levels used in this project, the required minimum clearance was determined as 0.2 mm, including an additional safety margin. Therefore, the general design rule of 0.2 mm minimum spacing was also sufficient with respect to creepage and clearance requirements. Nevertheless, larger distances were preferred in the power stage wherever the available board space allowed it, especially around the 24 V input path, the fuse, the MOSFETs, the freewheel diode and the motor connector. The current carrying capability of the power traces was checked according to IPC-2221 [7]. The required conductor width was calculated from the expected motor current and the permissible temperature rise of the copper trace. The empirical IPC-2221 relation can be written as [7]

I = k∆T

bA

c
, | (2.44)

where I is the current, ∆T is the allowed temperature rise and A is the trace cross-sectional area. The constants k, b and c depend on whether the trace is located on an external or internal layer. Solving this relation for the required cross-sectional area gives

A =

I
k∆Tb

1
c
. | (2.45)

With the copper thickness tCu, the required trace width follows from

w =

A

tCu

. | (2.46)

For the selected operating point, this calculation resulted in a minimum required conductor width of approximately 0.35 mm. This value is above the manufacturing minimum of 0.2 mm.

However, the actual PCB layout uses substantially wider copper areas for the main 24 V, ground and motor current paths. The IPC-2221 result was therefore used as a lower bound rather than as the final trace width. Particular attention was paid to the arrangement of the input capacitors and the half-bridge power path. The electrolytic capacitors and ceramic decoupling capacitors are placed close to the 24 V supply rail in order to reduce the effective loop impedance and to provide local energy storage for the switching stage [1]. This is important because the motor current is pulsed by the PWM operation and causes current ripple in the supply path. By placing the bulk capacitance close to the power stage, the high-frequency current loop can be shortened and the voltage ripple at the switching node can be reduced. The MOSFETs, freewheel diode and shunt resistor were placed in the right-hand power section of the PCB. This keeps the high-current path compact and avoids routing the motor current through the control section. The gate driver is located close to the MOSFET gates to reduce the gate loop length and to improve switching behavior, in accordance with the layout guidelines for high-side MOSFET drivers [4]. The bootstrap components and gate resistors are also placed near the driver and the MOSFETs, because these components are directly involved in the fast switching process. In contrast, the Arduino Nano and the user interface connectors are placed away from the main power path to reduce coupling from switching currents into the control electronics [5]. The PCB layout also considers thermal aspects. The thermal analysis identified the high-side MOSFET and the freewheel diode as the most critical components. Therefore, these components were connected to larger copper areas to improve heat spreading into the PCB [7]. The wide 24 V and ground copper regions not only reduce ohmic losses, but also act as local heat-spreading structures. Since the board is limited to two copper layers, the available copper area is an important part of the passive thermal management strategy. The PCB design follows a functional separation between the power stage, the voltage regulation and the control electronics. The high-current path is routed with wide copper regions, while the signal traces are kept shorter and separated from the switching node where possible. The minimum manufacturing requirements from the EMA-Lab design rules are fulfilled, and the electrical clearance was checked against EN 60664-1:2003. The IPC-2221 trace width calculation shows that the theoretical minimum conductor width is below the actually used copper areas in the power path. Therefore, the layout provides additional margin with respect to current carrying capability, voltage clearance and thermal spreading.

# Chapter 3

# Software Design

The software of the motor controller was designed as a state-based embedded control system. Its main tasks are the safe activation of the motor output, the generation of the PWM duty cycle, the measurement and filtering of the motor current, the closed-loop current control and the supervision of critical operating conditions. The implemented software structure is based on four main states: Idle, Start, Run and Fault. In the Idle state, the PWM output is disabled and the motor is not driven. This state is entered after power-up and after a controlled stop command. The Start state is used to perform a soft start, where the duty cycle or current reference is increased gradually instead of applying the full command immediately. After the soft-start phase is completed, the controller enters the Run state, where the PI current controller determines the PWM duty cycle during normal operation. The Fault state is entered if a critical condition such as an overcurrent or a locked motor condition is detected. In this state, the PWM output is disabled in order to prevent damage to the power electronics, the motor and the supply path. The controller can resume operation only after the fault condition has been removed and the system has returned to a safe operating range. The resulting state machine is shown in Figure 3.1. The state machine separates normal operation from startup and fault handling. This is important because the motor driver must not generate uncontrolled PWM signals during initialization or during a detected fault condition. The soft start is implemented to reduce electrical and mechanical stress during

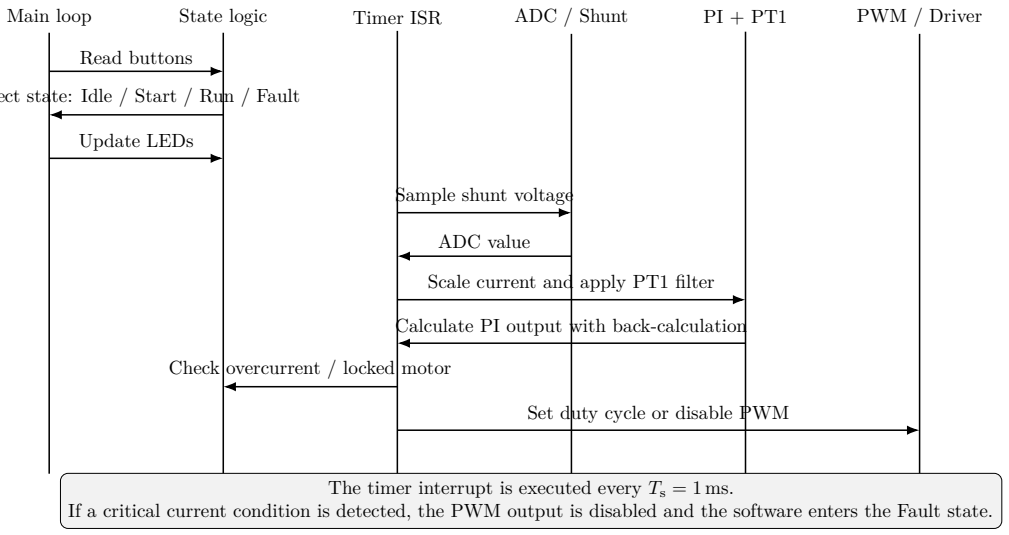
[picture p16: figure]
Main loop; State logic; Timer ISR; ADC / Shunt; PWM / Driver; Read buttons; Update LEDs; Sample shunt voltage; ADC value; Scale current and; apply PT1 filter; Calculate PI output with back-calculation; Check; overcurrent / locked; motor; Set duty cycle or disable PWM

Select state: Idle / Start / Run / Fault

The timer interrupt is executed every Ts = 1 ms. If a critical current condition is detected, the PWM output is disabled and the software enters the Fault state.

Figure 3.1: Simplified sequence diagram of the embedded motor control software.

motor startup. Without a soft start, the motor current could rise abruptly because the motor initially has no back electromotive force. This may cause a high inrush current and increase the thermal stress of the MOSFETs, the diode, the shunt resistor and the motor winding. Therefore, the controller does not directly apply the final reference value. Instead, the reference is increased step by step until the commanded operating point is reached. With the sampling time Ts, the ramp can be described as

r[k] = min (r[k − 1] + ∆r, rcmd), | (3.1)

where r[k] is the limited reference value, rcmd is the commanded reference and ∆r is the maximum reference increment per control step. This approach ensures that the PI controller receives a smooth reference input and that the duty cycle does not jump to a high value immediately after enabling the motor. The control algorithm is executed in a timer interrupt service routine with a fixed sampling time of

Ts = 0.001 s. | (3.2)

This corresponds to a control frequency of 1 kHz. The same sampling time is used for the discrete PI controller and for the PT1 filter of the current measurement. Using a fixed interrupt period is important because the discrete controller coefficients are derived for this sampling time. If the control loop were executed with a variable period, the effective controller dynamics would change and the anti-windup behavior would no longer match the design assumptions. The current is measured indirectly by evaluating the voltage across the shunt resistor with the Arduino analog-to-digital converter. The ADC returns a digital value nADC, which is converted into an input voltage according to

VADC[k] = nADC[k]

NADC − 1

Vref, | (3.3)

where NADC is the ADC resolution and Vref is the analog reference voltage. If an amplifier with gain Gshunt is used, the motor current is calculated from the measured voltage by

imeas[k] = VADC[k] − Voffset

GshuntRshunt

. | (3.4)

Here, Rshunt is the shunt resistance and Voffset represents the measurement offset. This offset is required if the measurement circuit does not produce exactly zero volts at zero current or if a biased measurement is used. The calculated current is then filtered before it is used by the controller and the protection logic. The shunt signal is affected by PWM switching noise and ADC quantization noise. Therefore, a first-order low-pass filter is applied to the measured current. The continuous-time transfer function of the PT1 filter is

Gf(s) = 1
Tfs + 1
, | (3.5)

where Tf

is the filter time constant. A PT1 filter is suitable for this application because it reduces high-frequency measurement noise while preserving the slower current dynamics required by the controller. The filter was discretized using the Tustin approximation

s ≈

2
Ts

z − 1
z + 1
. | (3.6)

Substituting this approximation into the PT1 transfer function gives the discrete filter relation
y[k] = afy[k − 1] + bf (x[k] + x[k − 1]), | (3.7)

with
af =

2Tf − Ts
2Tf + Ts
, | (3.8)

and
bf =

Ts
2Tf + Ts
. | (3.9)

In this equation, x[k] is the unfiltered current value and y[k] is the filtered current value. The filter is implemented in incremental form by storing the previous input and output values between interrupt calls. For current control, a PI controller was selected instead of a PID controller. A proportional term reacts directly to the current error, while the integral term removes steady-state error. This is useful because the motor, the MOSFETs and the wiring introduce voltage drops that may otherwise lead to a persistent current error. A derivative term was not used because the derivative action would amplify the measurement noise of the shunt signal. Since the current measurement is already affected by PWM ripple and ADC noise, a PID controller would increase the sensitivity of the duty cycle to measurement disturbances. Therefore, the PI controller represents a more robust choice for this task. The continuous-time PI controller is given by

GPI(s) = Kp +

Ki
s
, | (3.10)

where Kp is the proportional gain and Ki

is the integral gain. Using the Tustin approximation, the controller can be implemented as an incremental discrete-time controller:

uPI[k] = uPI[k − 1] + b0e[k] + b1e[k − 1], | (3.11)

with
b0 = Kp +

KiTs
2
, | (3.12)

and
b1 = −Kp +

KiTs
2
. | (3.13)

The control error is defined as
e[k] = iref[k] − ifilt[k], | (3.14)

where iref[k] is the current reference after the soft-start ramp and ifilt[k] is the filtered current measurement. The controller output is limited to the valid PWM duty-cycle range. Therefore, the unsaturated duty cycle uPI[k] is converted into the applied duty cycle

D[k] = sat (uPI[k]), | (3.15)

with
0 ≤ D[k] ≤ Dmax. | (3.16)

Since the duty cycle is saturated, anti-windup is required to prevent the integral part of the PI controller from accumulating an unrealistically large value during saturation. For this purpose, back-calculation was used. The difference between the saturated controller output and the unsaturated controller output is fed back into the integrator path:

eaw[k] = D[k] − uPI[k]. | (3.17)

The anti-windup correction reduces the internal controller state when the actuator is saturated and therefore improves the recovery behavior once the controller leaves saturation. The structure of the current control loop is shown in Figure 3.2. The ADC measurement is converted into a current value, filtered by the PT1 filter and compared with the current reference. The PI controller with back-calculation then computes the PWM duty cycle. The resulting duty cycle is applied to the motor driver, while the same measured current is also used by the protection logic. The protection logic is executed together with the control loop. The most important mandatory fault cases are a locked motor and overcurrent conditions.

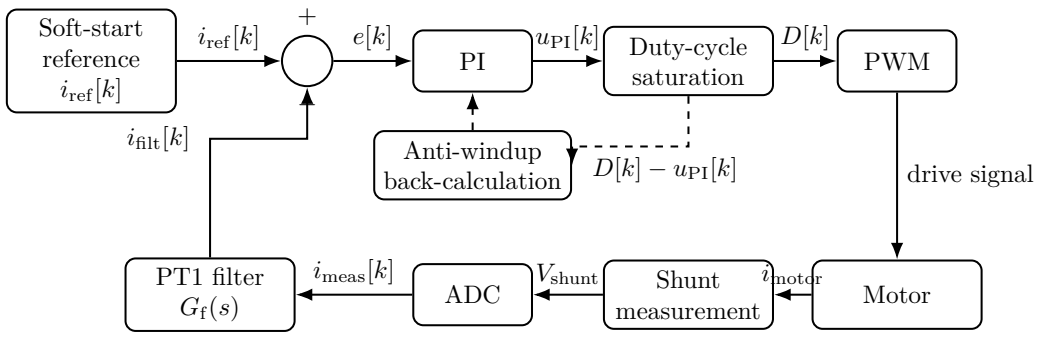
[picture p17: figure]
Soft-start reference iref[k]; Duty-cycle; saturation; PWM; Anti-windup back-calculation; Motor Shunt measurement ADC; PT1 filter Gf(s); iref[k]; uPI[k]; drive signal; Vshunt; imotor imeas[k]; ifilt[k]; D[k] − uPI[k]

Figure 3.2: Current control loop with shunt measurement, PT1 filtering, PI control, duty-cycle saturation and back-calculation anti-windup.

A locked motor can lead to a high current because the motor does not generate sufficient back electromotive force. Therefore, the software monitors the measured current and an accumulated I

2R-related load value. The instantaneous ohmic loss can be approximated by

PR[k] = i

2
filt[k]R, | (3.18)

where R represents the relevant resistance of the monitored current path. A simple accumulated stress value can be calculated as

ER[k] = ER[k − 1] + PR[k]Ts. | (3.19)

This value increases when a high current is present for a longer time. In practical implementation, this supervision may be combined with a direct current threshold to react quickly to severe overcurrent events:

ifilt[k] > imax. | (3.20)

If the threshold is exceeded or the accumulated load becomes too high, the controller enters the Fault state and disables the PWM output. This behavior addresses the requirement that a locked motor or overcurrent fault must not damage the system or its components. After the blockage has been removed and the measured current has returned to a safe range, the software can leave the Fault state through a reset or restart condition. The optional fault cases, such as overtemperature, overvoltage and undervoltage, were treated separately from the mandatory current-related protection. Since no dedicated temperature sensor or voltage monitoring channel was implemented in the basic software version, these functions were not part of the active fault handling. Their implementation would only be required if the risk assessment shows that the circuit can be damaged by these conditions without additional protection. In the present implementation, the main protective mechanism is therefore the current-based supervision of overcurrent and locked-motor conditions. The buttons and LEDs are integrated into the cyclic software execution. The buttons are used to enable or disable the motor output and to adjust the command value, for example by increasing or decreasing the reference. In order to avoid false triggering due to mechanical contact bounce, button states should be evaluated with a simple debounce mechanism or edge detection. The LEDs are used as optical indicators for the current software state and for detected faults. For example, an LED can indicate whether the controller is in Idle, Run or Fault. Additional indicators for overcurrent, speed-up or speed-down commands are optional according to the project requirements. The sequence of one software cycle is shown in Figure 3.1. The main loop handles non-time-critical tasks such as button evaluation, state transitions and LED updates. The timer interrupt provides the deterministic control timing. Inside the interrupt, the current measurement is sampled, converted, filtered and used by the

PI controller. The protection logic is evaluated before the PWM duty cycle is applied. If a fault is detected, the PWM output is disabled immediately and the state machine enters the Fault state. The software design therefore combines deterministic interrupt-based control with a state machine for safe operation. The 1 ms interrupt period defines the sampling time for the PT1 current filter and the discrete PI controller. The soft-start function prevents abrupt current commands during startup, while the PI controller with back-calculation generates a saturated PWM duty cycle without excessive integrator windup. The shunt-based current measurement is used both for closed-loop control and for protection against locked-motor and overcurrent conditions. Optional functions such as overtemperature, overvoltage and undervoltage detection can be added if additional sensors or measurement channels are included in the hardware. “‘latex

# Chapter 4
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

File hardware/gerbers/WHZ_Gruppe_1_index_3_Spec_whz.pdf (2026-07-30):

Uwe David
Westsächsische Hochschule Zwickau 08056 Zwickau, Kornmarkt 1 Deutschland
12.06.2026
Tel: +49 375 536 1408
uwe.david@whz.de

Platine WHZ Motor-Driver Team 1 Index 3 Juni 2026

- Dimensions: 130.0 x 93.0 mm
- 2-Layer
- Soldermask: Green, Matte
- Board thickness: 1.55 mm (Standard)
- Finished copper thickness: 0.35 mm (Standard)
- Silkscreen: Top side only
- Minimum track width: 0.2 mm
- Minimum via finished diameter: 0.25 mm

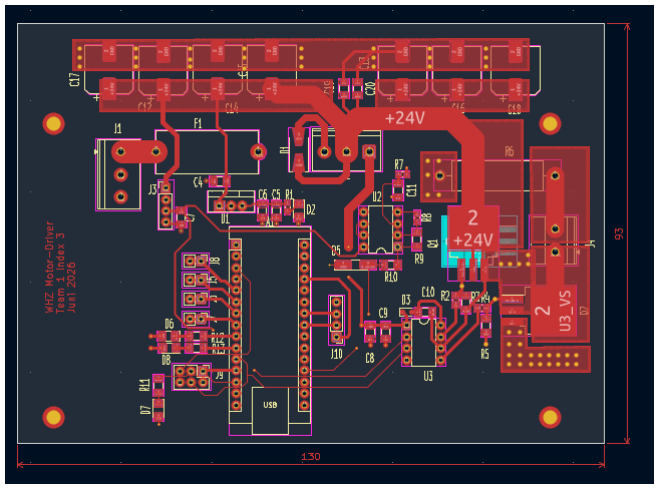
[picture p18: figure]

DK - Holes

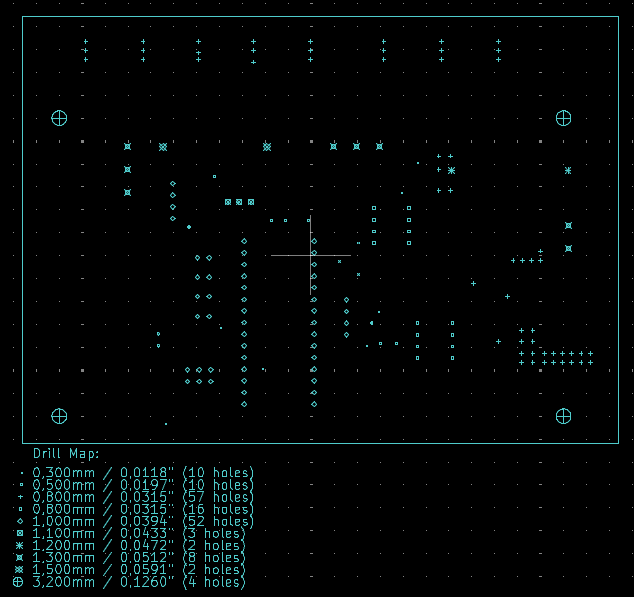
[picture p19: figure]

NDK 0 - Holes

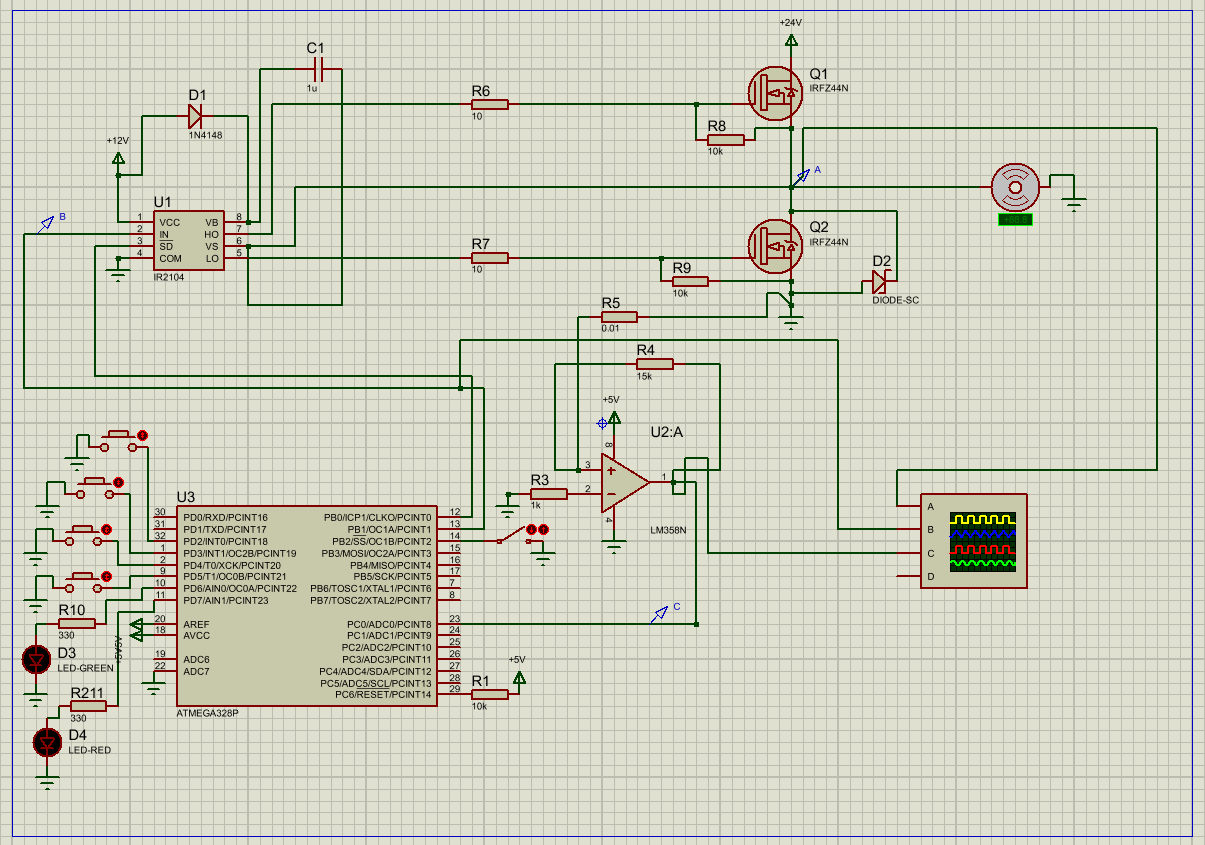
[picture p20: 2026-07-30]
simulation/proteus/Proteus Sim.png

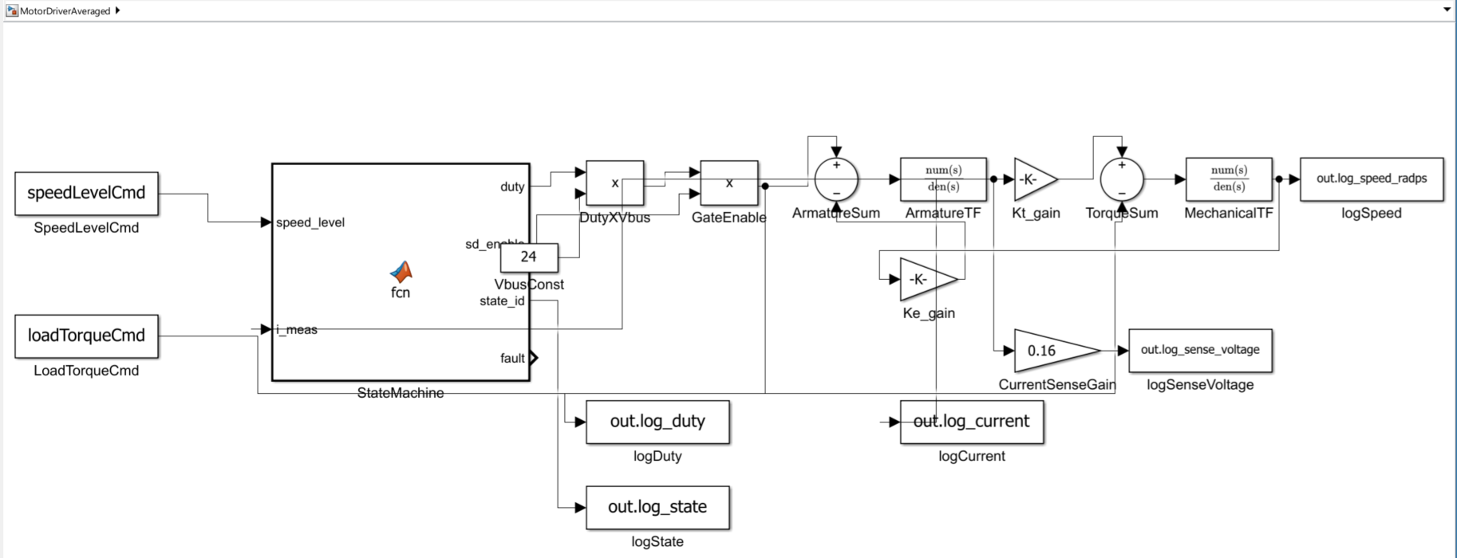
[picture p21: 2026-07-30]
simulation/simulink/Simulink.png

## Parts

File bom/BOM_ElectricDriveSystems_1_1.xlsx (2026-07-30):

Team 1
24V / 250W Brushed DC Motor Driver IR2104 Half-Bridge
Includes: PCB components, connection materials, mechanical hardware and motor
# | Reference | Qty | Value / Description | Spec | Source | Unit € (est.) | Total € | Notes
A — PCB ELECTRONIC COMPONENTS (from KiCad BOM)
A.1 — Power Stage
1 | Q1, Q2 | 2 | IRFZ44NSPBF MOSFET N-Ch | D²Pak, 55V 49A 0,0175Ω | https://www.reichelt.de/de/de/shop/produkt/mosfet_n-ch_55v_49a_0_0175r_d_pak-254808?PROVID=2788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 | €0.91 | €1.82 | Half-bridge switches
2 | D4 | 1 | MBRS2045CT Schottky diode | D²Pak, 20A 45V | https://www.reichelt.de/de/de/shop/produkt/smd-schottky_45v_20a_2x10_d_pak-378115?PROVID=2788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 | €0.90 | €0.90 | Freewheeling — CORRECTED from 1N5822
3 | F1 | 1 | LITT 0287015 | Littlefuse KFZ-Sicherung, ATO, 15 A, blau | https://www.reichelt.de/de/de/shop/produkt/kfz-sicherung_ato_15_a_blau-242164?PROVID=2788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 | €0.87 | €0.87 | Input protection
4 | D1 | 1 | P4SMAJ33CA | TVS-Diode, bidirektional, 33 V, 400 W, DO-214AC/SMA | https://www.reichelt.de/de/de/shop/produkt/tvs-diode_bidirektional_33_v_400_w_do-214ac_sma-272868?PROVID=2788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 | €0.10 | €0.10 | 24V transient clamp
5 | D3 | 2 | BAS 16J | SMD Si all-purpose diodes, SOD323F, 100 V, 0.25 A | https://www.reichelt.com/ie/en/shop/product/smd_si_all-purpose_diodes_sod323f_100_v_0_25_a-95203&utm_medium=&utm_campaign=&track_id=&country=ie&CCTYPE=private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 | €0.03 | €0.06 | Bootstrap diode
6 | D5 | 1 | nexperia BZV 55-C5V1 NXP | Zenerdiode, 5,1 V, 0,5 W, SOD-80 | https://www.reichelt.de/de/de/shop/produkt/zenerdiode_5_1_v_0_5_w_sod-80-219417?PROVID=2788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 | €0.02 | €0.02 | Voltage reference/protection
2026-05-01 |  | 2 | fischer Elektronik FK 244 13 D2 PAK | Kühlkörper, 13 mm, Kupfer, 22,8 K/W, PowerSO-10/SO-14/SO-16/SO-8 | https://www.reichelt.de/de/de/shop/produkt/kuehlkoerper_13_mm_kupfer_22_8_k_w_powerso-10_so-14_so-16_so-8-228050 | €0.99 | €1.98 | Kühlkörper für D2Pak Mosfets
A.2 — Voltage Regulation
7 | U1 | 1 | L7812CV STM 12V linear regulator | TO-220 | https://www.reichelt.de/de/de/shop/produkt/spannungsregler_fest_12_v_1_5a_4_to-220-216569?PROVID=2788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 | €0.23 | €0.23 | Mandatory: IR2104 VCC (UVLO 8.2V)
8 | J3 | 1 | LM2596S DEBO DCDC 2.5W | Entwicklerboards - Spannungsregler 2,5 W, DC/DC-Wandler, LM2596S, 4-pin header module | https://www.reichelt.de/de/de/shop/produkt/entwicklerboards_-_spannungsregler_2_5_w_dc_dc-wandler_lm2596s-282576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 | €2.99 | €2.99 | 24V → 5V for Arduino
A.3 — Control & Driver
9 | A1 | 1 | Arduino Nano v3.x (ATmega328P) | Module, 16 MHz, 5V |  |  | €0.00 | Main controller
10 | U3 | 1 | IR2104 half-bridge gate driver | DIP-8 | https://www.reichelt.de/de/de/shop/produkt/brueckentreiber_halbbruecke_so-8-115928?PROVID=2788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 | €1.30 | €1.30 | 520ns deadtime, SD pin
11 | U2 | 1 | LM 358 DIP dual op-amp | DIP-8 | https://www.reichelt.de/de/de/shop/produkt/operationsverstaerker_2-fach_dip-8-10483?PROVID=2788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 | €0.25 | €0.25 | Current sense amplifier (G≈16)
A.4 — Capacitors
12 | C1 | 8 | ELKO-Polymere Hybrid SMD, 100 µF, 50 V, 145°C | 10,0 x 10,2 mm | https://www.reichelt.de/de/de/shop/produkt/elko-polymere_hybrid_smd_100_f_50_v_145_c_10_0_x_10_2_mm-228600 | €1.70 | €13.60 | Input bulk decoupling, eliminating ripple current
14 | C3, C6, C7,C9,C11 | 10 | Wasin 1206B104K500CT | SMD-Kerko, 1206, 100 nF, 50V, 10%, X7R, MLCC | https://www.reichelt.de/de/de/shop/produkt/smd-kerko_1206_100_nf_50v_10_x7r_mlcc-346850 | €0.07 | €0.70 | IC decoupling
15 | C4 | 5 | Wasin WAL 1206B334K500 | SMD-Kerko, 1206, 330 nF, 50V, 10%, X7R, MLCC | https://www.reichelt.de/de/de/shop/produkt/smd-kerko_1206_330_nf_50v_10_x7r_mlcc-346856 | €0.07 | €0.35
16 | C5 | 10 | Samsung CL31B106KBHNNNE | MLCC, 1206, 10uF, 50V, X7R, ±10%, H1,6 mm | https://www.reichelt.de/de/de/shop/produkt/mlcc_1206_10uf_50v_x7r_-10_h1_6_mm-429149 | €0.46 | €4.60
17 | C2, C8, C10 | 10 | muRata GRM31CR72A105K | MLCC, 1206, 1µF, 100 V, ±10%, X7R | https://www.reichelt.de/de/de/shop/produkt/mlcc_1206_1_f_100_v_-10_x7r-409216 | €0.14 | €1.40 | Bootstrap capacitors
A.5 — Resistors
20 | R1, R7, R8 | 3 | RND 0603 1 93,1K | SMD-Widerstand, 0603, 93,1 kOhm, 100 mW, 1% | https://www.reichelt.de/de/de/shop/produkt/smd-widerstand_0603_93_1_kohm_100_mw_1_-213152?PROVID=2788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 | €0.02 | €0.06 | Pull-up / general
21 | R2, R4 | 2 | RND 1550805 AH | SMD-Widerstand, 0805, 10 Ohm, 125 mW, 5% | https://www.reichelt.de/de/de/shop/produkt/smd-widerstand_0805_10_ohm_125_mw_5_-250225?PROVID=2788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 | €0.02 | €0.04 | Gate resistors (di/dt limit)
22 | R3, R5 | 2 | Wasin WAL WR12X1002FTL | SMD-Widerstand, 1206, 10 kOhm, 250 mW, 1% | https://www.reichelt.de/de/de/shop/produkt/smd-widerstand_1206_10_kohm_250_mw_1_-346640?PROVID=2788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 | €0.02 | €0.04 | Gate pull-downs
23 | R6 | 1 | VIT KN350-85B0R1 | VIT KN350-85B0R1 | https://www.reichelt.de/de/de/shop/produkt/drahtwiderstand_axial_4_w_0_01_ohm_5_-233356 | €0.75 | €0.75 | Current sense shunt
24 | R9 | 1 | Waisin WAL WR12X1502FTL | SMD-Widerstand, 1206, 15 kOhm, 250 mW, 1% | https://www.reichelt.de/de/de/shop/produkt/smd-widerstand_1206_15_kohm_250_mw_1_-346648 | €0.02 | €0.02 | Op-amp gain (1k+15k=G16)
25 | R10 | 1 | Vishay VIS CRCW12061002 | SMD-Widerstand, 1206, 100 Ohm, 250 mW, 1% | https://www.reichelt.de/de/de/shop/produkt/smd-widerstand_1206_100_ohm_250_mw_1_-238101 | €0.09 | €0.09 | LED current limit
26 | R11, R12, R13 | 3 | Wasin WR12X3300FTL | SMD-Widerstand, 1206, 330 Ohm, 250 mW, 1% | https://www.reichelt.de/de/de/shop/produkt/smd-widerstand_1206_330_ohm_250_mw_1_-346670 | €0.02 | €0.06 | Status LED resistors
A.6 — LEDs & Indicators
27 | D2 | 2 | Everlight EVL 11-21SYGC | SMD-LED 1206, Super-Gelb-Grün, AlGaInP, 29 mcd, 60°, 3,0 x 1,5mm | https://www.reichelt.de/de/de/shop/produkt/smd-led_1206_super-gelb-gruen_algainp_29_mcd_60_3_0_x_1_5mm-231610 | €0.05 | €0.10 | Power-on indicator
 |  | 1 | EVL 11-21SURC/S2 | LED, SMD 1206, rot, 180 mcd, 60° | https://www.reichelt.de/de/de/shop/produkt/led_smd_1206_rot_180_mcd_60_-231609 | €0.07
28 | D6, D7, D8 | 1 | Huiyuan 1206Y1C-KHA-C | LED, SMD 1206, gelb, 150 mcd, 120° | https://www.reichelt.de/de/de/shop/produkt/led_smd_1206_gelb_150_mcd_120_-361548 | €0.09 | €0.09 | Status: run / fault / PWM
A.7 — PCB Connectors
29 | J1 | 1 | 24V_IN screw terminal DG127 5,08-2 | Phoenix MKDS 1.5/2 P5mm | https://www.reichelt.de/de/de/shop/produkt/leiterplattenklemme_2_polig_rm_5_08_mm-276156 | €0.33 | €0.33 | 24V input
30 | J2 | 1 | MAIN_PWR screw terminal DG127 5,08-2 | Phoenix MKDS 1.5/2 P5mm | https://www.reichelt.de/de/de/shop/produkt/leiterplattenklemme_2_polig_rm_5_08_mm-276156 | €0.33 | €0.33 | Main power bus
31 | J4 | 1 | Motor output screw terminal DG127 5,08-2 | Phoenix MKDS 1.5/2 P5.08mm | https://www.reichelt.de/de/de/shop/produkt/leiterplattenklemme_2_polig_rm_5_08_mm-276156 | €0.33 | €0.33 | Motor M+/M−
32 | J5, J6, J7 | 3 | MPE 087-1-002 | PinHeader 1×02 P2.54mm | https://www.reichelt.de/de/de/shop/produkt/stiftleisten_2_54_mm_1x02_gerade-119879 | €0.06 | €0.18 | Signal jumpers
33 | J8 | 1 | BTN_ON 2-pin header | PinHeader 1×02 P2.54mm | https://www.reichelt.de/de/de/shop/produkt/stiftleisten_2_54_mm_1x02_gerade-119879 | €0.06 | €0.06 | ON button input
34 | J9 | 1 | ISP/button 2×3 header MPE 087-2-006 | PinHeader 2×03 P2.54mm | https://www.reichelt.de/de/de/shop/produkt/stiftleisten_2_54_mm_2x03_gerade-119893 | €0.16 | €0.16 | Programming / button input
 |  | 2 | BKL Electronic BKL 10120953 | Buchsenleiste 2,54mm 1x16 gerade | https://www.reichelt.de/de/de/shop/produkt/buchsenleiste_2_54mm_1x16_gerade-266678 | €0.99 | €1.98 | Arduino Pinverbindung
35 | — | 1 | Fuse holder 5×20mm | Horizontal open mount | https://www.reichelt.de/de/de/shop/produkt/sicherungshalter_fuer_5_x_20_mm_250_v_6_3_a-243307?PROVID=2788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 | €0.27 | €0.27 | For F1
SUBTOTAL A — PCB Components |  |  |  |  |  |  | €36.06 | ~50 individual components
B — CONNECTION MATERIALS (per Project Hints Appendix 5)
B.1 — Cables & Wires
36 | W1 | 1 | 12 AWG / 4mm² silicone wire RED (5m) | Stranded, 600V rated | https://www.amazon.de/QWORK%C2%AE-12AWG-Silikon-Elektronik-Kabel/dp/B0C9MBMM76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 | €11.99 | €11.99 | 24V power bus, motor+, ≥15A capable
37 | W2 | 1 | 12 AWG / 4mm² silicone wire BLACK (5m) | Stranded, 600V rated | https://www.amazon.de/QWORK%C2%AE-12AWG-Silikon-Elektronik-Kabel/dp/B0C9MBMM76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 | €11.99 | €11.99 | GND return, motor−
 |  | 1 | DEBO OLED2 0.96 | Entwicklerboards - Display, 0,96", OLED-Display, SSD1306 | https://www.reichelt.de/de/de/shop/produkt/entwicklerboards_-_display_0_96_oled-display_ssd1306-266107 | €6.99 | €6.99
38 | W3 | 1 | 22 AWG / 0.34mm² hookup wire set (6 colors) | 10m per color | https://www.amazon.de/Fermerry-Litzendraht-Kupferdrahtspule-10-Elektrokabel-Kit/dp/B09BFPHRZ6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 | €14.89 | €14.89 | Signal: buttons, LEDs, I²C, ADC
39 | W4 | 1 | 18 AWG / 1mm² wire RED+BLACK (3m each) | Stranded | https://www.reichelt.de/de/de/shop/produkt/lautsprecherkabel_2x1_5_mm_10_m_rot_schwarz_cca-364143?PROVID=2788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 | €3.10 | €3.10 | 12V/5V regulation bus
B.2 — Off-Board Connectors
40 | CON1 | 1 | XT60 panel-mount pair + pigtails | Male+Female, 60A rated | https://www.reichelt.de/de/de/shop/produkt/steckverbinder_fuer_li-polymer-akkus_2-polig_xt60_mit_kappe-342796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 | €2.99 | €2.99 | Battery / PSU input connector
41 | CON2 | 2 | 4mm banana socket panel-mount (Red+Black) | 4mm, 32A rated | https://www.reichelt.de/de/de/shop/produkt/einbaubuchse_4_mm_faston_rot_gesichert-106130?PROVID=2788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 | €1.85 | €3.70 | Test points for lab PSU probes
42 | CON3 | 1 | GX16-2 aviation connector pair | 2-pin, 15A rated | https://www.amazon.de/MSCHENZW-Verbinder-2-Poliger-Schrauben-Anschluss/dp/B0D7CLRNP4 | €2.99 | €2.99 | Motor disconnect (optional but clean)
B.3 — Terminals & Crimps
43 | T1 | 4 | Screw terminal block 5.08mm 2-pole (spare) | 15A rated | https://www.reichelt.de/de/de/shop/produkt/leiterplattenklemme_2_polig_rm_5_08_mm-276156 | €0.33 | €1.32 | Spares for PCB + motor wiring
44 | T2 | 1 | Crimp ferrule kit 0.5–6mm² | ~100 pcs assorted | https://www.reichelt.de/de/de/shop/produkt/aderendhuelsen-sortiment_isoliert_0_5_-_2_5_mm_-24731?PROVID=2788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 | €4.90 | €4.90 | All wire ends get ferrules
45 | T3 | 1 | Heat-shrink tubing assortment | 100 pcs, 2:1 ratio | https://www.reichelt.de/de/de/shop/produkt/schrumpfschlauch-sortiment_2_1_10cm_100st_-149031?PROVID=2788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 | €3.50 | €3.50 | Insulation on splices & terminals
46 | T4 | 20 | Ring terminal kit M3/M4 (4mm²) | 20 pcs | https://www.reichelt.de/de/de/shop/produkt/ring-kerbschuhe_fuer_m4_rot-231392?PROVID=2788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 | €0.20 | €4.00 | Motor terminals, grounding points
B.4 — Cable Management
47 | CM1 | 1 | Cable tie pack (100mm + 200mm) | 100 pcs mixed | https://www.reichelt.de/de/de/shop/produkt/kabelbinder_uv-bestaendig_100_mm_schwarz_100er-pack-24764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 | €0.50 | €0.50 | Wire routing & strain relief
48 | CM2 | 20 | Self-adhesive cable clip set | 20 pcs, for wood screw | https://www.reichelt.de/de/de/shop/produkt/kabelhalter_selbstkleb_verstellbar_16_5-20_1_sw-114110?PROVID=2788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 | €0.37 | €7.40 | Route wires along board edges
49 | CM3 | 1 | Spiral wrap 6mm × 2m | PE, black | https://www.reichelt.de/de/de/shop/produkt/spiralschlauch_6_mm_schwarz_10_m-424800?PROVID=2788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 | €1.45 | €1.45 | Bundle power cables neatly
SUBTOTAL B — Connection Materials |  |  |  |  |  |  | €81.71
C — MECHANICAL & MOUNTING HARDWARE
C.1 — Board & Fasteners
50 | BD1 | 1 | Plywood board 400×300×12mm | Birch plywood, sanded |  | €14.76 | €14.76 | Main assembly board
51 | BD2 | 1 | M3 brass standoff set (F-F 10mm) | 10 pcs + M3×6 screws + washers | https://www.reichelt.de/de/de/shop/produkt/arduino_-_abstandshalter-sortiment_m3_0-223624?PROVID=2788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 | €13.20 | €13.20 | PCB mounting to board
52 | BD3 | 10 | M4 × 16mm wood screws + washers | 10 pcs | https://www.reichelt.de/de/de/shop/produkt/pan_head_schrauben_kreuzschlitz_pzd_m4_16mm_50_stueck-65757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 | €1.99 | €19.90 | Corner mounting / board feet
53 | BD4 | 0 | M3 × 16mm wood screws + washers | 10 pcs | https://www.reichelt.de/de/de/shop/produkt/pan_head_schrauben_kreuzschlitz_pzd_m3_16mm_50_stueck-65754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 | €1.72 | €0.00 | PCB standoffs to wood | bitte nicht beachten, außer die Box ist zu teuer
 |  | 0 | M3 Abstandshalter |  | https://www.ebay.de/itm/198316043017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 | €5.55 | €0.00
53 | BD4 | 1 | M3 Spacer, etc. | 680Stk M3 Abstandshalter Hex Distanzhülsen PCB Standoff Schraube Mutter Spacer Abstandsbolzen für Platine Raspberry Pi Mainboard PCB Board,M3 Messing Männlich Weiblich Sechskantschrauben Mutter | https://www.amazon.de/Abstandshalter-Distanzh%C3%BClsen-Abstandsbolzen-Raspberry-Sechskantschrauben/dp/B0D47H53ZF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 | €14.59 | €14.59
54 | BD5 | 4 | Rubber feet (self-adhesive) | Ø15mm, 5mm height | https://www.reichelt.de/de/de/shop/produkt/klebefuesse_20_6_mm_5_mm_schwarz_6er-pack-53677?PROVID=2788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 | €1.90 | €7.60 | Anti-slip for board underside
C.2 — Switches & Buttons (Panel-Mount)
55 | SW1 | 1 | Main toggle switch 16A 250V | SPST latching, panel-mount | https://www.reichelt.de/de/de/shop/produkt/kippschalter_16_4_a-250vac_1x_aus-ein-105728?PROVID=2788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 | €2.60 | €2.60 | Main power disconnect
56 | SW2–SW5 | 4 | Push button 12mm momentary (4 colors) | PBS-33B or similar, panel-mount | https://www.amazon.de/OTOTEC-Montage-Wasserdicht-Momentary-PBS-33B/dp/B0F37PFFNG | €2.29 | €9.16 | START / STOP / SPEED+ / SPEED−
C.3 — Thermal Management
57 | HS1 | 2 | Heatsink for IRFZ44N (TO-220) | Fischer SK 129 38.1mm | https://www.reichelt.de/de/de/shop/produkt/kuehlkoerper_38_1_mm_alu_6_5_k_w_sot-32_to-220_to-3p-228064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 | €2.70 | €5.40 | MOSFET cooling
58 | HS2 | 1 | Heatsink for L7812 (TO-220) | Fischer SK 104 38.1mm | https://www.reichelt.de/de/de/shop/produkt/kuehlkoerper_38_1_mm_alu_11_k_w_sot-32_to-220-228946?PROVID=2788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 | €1.99 | €1.99 | 0.6W dissipation — margin
59 | HS3 | 1 | Thermal grease Arctic MX-4 4g | Thermal conductivity 8.5W/mK | https://www.amazon.de/-/en/ARCTIC-MX-4-conductivity-non-conductive-non-capacitive/dp/B07L9BDY3T | €5.49 | €5.49 | MOSFET + regulator interface
C.4 — LED Panel Holders
60 | LH1 | 4 | 5mm LED panel mount holder (chrome bezel) | Snap-in, for D2/D6/D7/D8 | https://www.reichelt.com/de/en/shop/product/led_holder_for_5_mm_leds_chrome_black-232296 | €7.55 | €30.20 | Clean LED mounting in top zone
SUBTOTAL C — Mechanical & Mounting |  |  |  |  |  |  | €124.89
DC MOTOR
61 | M1 | 1 | MY1016 24V 250W brushed DC motor | Ø~65mm, 3000 RPM, 13.7A rated |  |  | €0.00 | Main drive motor
62 | M2 | 1 | Motor mounting bracket / L-bracket | Steel, 2× M6 holes | https://www.amazon.de/-/en/TuToy-Motor-L-shaped-Bracket-Support/dp/B0828NPDH6 | €11.56 | €11.56 | Secure motor to board
63 | M3 | 1 | 100nF 100V ceramic disc cap | Solder to motor brush tabs | https://www.reichelt.com/de/en/shop/product/ceramic_capacitor_100_nf_-20_80_y5v_50_100_v_rm_5-9265 | €0.04 | €0.04 | Brush noise suppression (critical!)
SUBTOTAL D — Motor |  |  |  |  |  |  | €11.60
PCB FABRICATION
64 | PCB1 | 1 | PCB fabrication 5 pcs (400×300mm 2-layer) | 1.6mm FR4, HASL-LF, 2oz Cu |  |  | €0.00 | Includes DHL shipping to DE
SUBTOTAL E — PCB Fabrication |  |  |  |  |  |  | €0.00
GRAND TOTAL (A + B + C + D + E) |  |  |  |  |  |  | €254.26
BUDGET ALLOCATED |  |  |  |  |  |  | €400.00
SAVINGS (Budget − Total) |  |  |  |  |  |  | €145.74

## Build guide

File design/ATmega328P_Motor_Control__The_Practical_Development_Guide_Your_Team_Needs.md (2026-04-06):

# ATmega328P motor control: the practical development guide your team needs

**Proteus 9 is already the best simulation tool for your motor control project — no alternative comes close for mixed-signal work.** The real gains lie elsewhere: switching to PlatformIO for builds, adopting a dual-target testing strategy, and setting up lightweight CI/CD. As for the ARM cross-compilation question, it's definitively irrelevant to ATmega328P — your teammate is almost certainly confusing the classic Nano with one of Arduino's newer ARM-based Nano boards. Here's the complete breakdown.

## PC-based ATmega328P emulation exists, but none replaces Proteus

Four tools can emulate ATmega328P firmware on a PC without hardware. Each serves a different purpose, and none comes within striking distance of Proteus for motor control simulation.

**SimAVR** is the most capable open-source option. It's a cycle-accurate AVR emulator written in C that directly loads ELF files and supports ATmega328P at 16 MHz with full GDB debugging (breakpoints, stepping, variable inspection via `avr-gdb` on `localhost:1234`). It handles UART, SPI, ADC, external interrupts, and can dump pin states to VCD waveform files viewable in GTKWave. PlatformIO packages it as `tool-simavr` for automated unit testing. The critical limitation for motor control: **Phase Correct PWM mode is listed as TODO**. Fast PWM works, but the simulator operates at a "logical level" — it reports duty cycle/frequency as values rather than toggling output pins. External peripherals (motors, H-bridges) must be hand-coded in C. The project is in low-maintenance mode as of 2025 with community-driven patches only.

**QEMU AVR** merged into mainline QEMU in version 5.1 (August 2020) and supports `qemu-system-avr -M uno` for ATmega328P. The CPU instruction set is complete, but peripheral emulation is **extremely immature**: only USART and a partial 16-bit timer are implemented. ADC, GPIO, 8-bit timers (Timer0/Timer2), SPI, I2C, external interrupts, and PWM are all missing. Even Arduino's `delay()` doesn't work because Timer0 isn't emulated. Development progress on AVR peripherals has been essentially stagnant since 2020. **Skip QEMU entirely** for motor control.

**Wokwi** is a browser-based simulator built on avr8js, a JavaScript AVR8 emulator providing cycle-accurate ATmega328P emulation. It explicitly supports Arduino Nano and includes servo motors, stepper motors, A4988 drivers, potentiometers, displays, and a logic analyzer. The VS Code extension integrates with PlatformIO: compile locally, simulate visually with GDB debugging. The free tier requires public projects; paid plans start at **$7/month**. The gap for your project: **no L293D/L298N H-bridge, no DC motor model, and no analog/SPICE simulation**. Wokwi is a functional/behavioral simulator, not a mixed-signal one — it cannot show back-EMF, current draw, or switching transients.

**PlatformIO** is not a simulator itself but integrates with both SimAVR (for headless unit testing and GDB debugging) and Wokwi (for visual simulation in VS Code). Its value is as the build system connecting your code to these tools.

The bottom line: **Proteus 9 Professional is irreplaceable for your use case.** It co-simulates SPICE analog circuits alongside MCU firmware execution, meaning you see actual voltage waveforms on PWM pins, current through H-bridge transistors, motor dynamics, and back-EMF — simultaneously with firmware stepping. It has **750+ MCU models**, thousands of electrical components (including L293D, L298N, DC motors, servos), virtual oscilloscopes, logic analyzers, and protocol decoders. No open-source or free tool replicates this. Adding Wokwi or SimAVR alongside Proteus offers marginal benefit: faster iteration for firmware logic (Wokwi), or automated regression testing (SimAVR via PlatformIO), but neither adds capability for the electrical/motor aspects your project needs.

## ARM cross-compilation is categorically wrong for ATmega328P

The ATmega328P is an **8-bit AVR architecture** chip using the AVR instruction set, compiled with `avr-gcc` (flag: `-mmcu=atmega328p`), and uploaded with `avrdude`. It has absolutely nothing to do with ARM. When the Arduino IDE or PlatformIO compiles code for ATmega328P, it IS cross-compiling — but the target is AVR, not ARM. Using `arm-none-eabi-gcc` would produce machine code completely incompatible with the ATmega328P's CPU.

The most likely source of confusion is **Arduino's Nano product line**, which now includes nine boards spanning four different architectures:

| Board | Processor | Architecture | ARM? |
|---|---|---|---|
| Nano (classic) | ATmega328P | 8-bit AVR | No |
| Nano Every | ATmega4809 | 8-bit megaAVR | No |
| Nano 33 IoT | SAMD21 | ARM Cortex-M0+ | **Yes** |
| Nano 33 BLE | nRF52840 | ARM Cortex-M4F | **Yes** |
| Nano RP2040 Connect | RP2040 | ARM Cortex-M0+ | **Yes** |
| Nano ESP32 | ESP32-S3 | Xtensa LX7 | No |
| Nano R4 | Renesas RA4M1 | ARM Cortex-M4 | **Yes** |
| Nano Matter | MGM240S | ARM Cortex-M33 | **Yes** |

Five of nine Nano-family boards genuinely are ARM-based. A teammate reading about "Arduino Nano" development could easily encounter ARM cross-compilation instructions meant for the Nano 33 BLE or Nano RP2040 and assume it applies to the classic Nano. Another probable source: **STM32 motor control resources**. STMicroelectronics markets the STM32G4 (ARM Cortex-M4 at 170 MHz) specifically for motor control with dedicated FOC libraries, and these are extremely prominent in motor control literature. Someone researching motor control firmware may conflate STM32/ARM techniques with the ATmega328P project.

There are narrow edge cases where ARM appears legitimately in an AVR project — using a Raspberry Pi (ARM) as the build host, or a multi-board system where an ARM processor handles high-level control while the ATmega328P drives PWM. But in all these cases, the ATmega328P target still compiles with `avr-gcc`. **The recommendation: clarify with the teammate which board they mean, and correct the terminology if it's genuinely an ATmega328P project.**

## PlatformIO is the right development environment for this team

For a Master's student team in 2025–2026, **PlatformIO with VS Code is the clear choice** over Arduino IDE 2.x or bare avr-gcc. Here's why each option falls where it does.

Arduino IDE 2.3.7 (released December 2025) added IntelliSense via clangd, a built-in debugger, and modernized the UI. But it retains fundamental limitations: a single-sketch paradigm with no formal project structure, global library management prone to version conflicts, no unit testing framework, no CI/CD integration, and compilation outputs go to unpredictable temp directories. For a single person experimenting, it's fine. For a team project with version control, it creates friction.

PlatformIO uses `avr-gcc` under the hood (packaged as `toolchain-atmelavr`) with the standard Arduino framework — your code stays 100% Arduino-compatible. The difference is everything around the compiler. The `platformio.ini` file makes builds **deterministic and reproducible**: every team member cloning the repo gets identical toolchain versions, library versions, and build flags automatically downloaded. The output lands at a predictable path (`.pio/build/nanoatmega328/firmware.hex`) that you set once in Proteus and never touch again. Multi-environment support lets you define both an AVR target and a native desktop target in the same project for testing. Incremental builds run **3–4× faster** than Arduino IDE's full recompilation. And the CLI (`pio run`, `pio test`, `pio run -t upload`) integrates directly into CI pipelines.

A practical `platformio.ini` for your project:

```ini
[platformio]
default_envs = nanoatmega328

[env:nanoatmega328]
platform = atmelavr
board = nanoatmega328
framework = arduino
monitor_speed = 115200
build_flags = -Wall -Wextra

[env:native]
platform = native
test_framework = googletest
lib_deps = fabiobatsilva/ArduinoFake@^0.4
build_flags = -std=c++17
```

## The dual-target testing strategy catches bugs without hardware

The most valuable technique for your team is **dual-target compilation**: the same codebase compiles for AVR (production firmware) and for your desktop (native unit tests). This requires one architectural discipline — **separating hardware-dependent code from pure logic**.

Structure the project so the PID controller, state machine, and control algorithms live in standalone libraries with no Arduino dependencies. These compile natively with desktop GCC and get tested with **GoogleTest** using full assertion power, mocking, and parameterized tests. The motor driver, encoder reader, and pin-level I/O live in separate modules that use Arduino APIs. For native testing, **ArduinoFake** provides mock implementations of `digitalWrite`, `analogRead`, `Serial`, and other Arduino functions, letting you verify that your logic calls the right hardware functions with the right arguments — without touching real hardware.

For on-device testing (when you do have hardware), **Unity** is the right framework for AVR's constrained 2 KB of SRAM. PlatformIO's built-in test runner compiles test firmware, uploads it, reads Serial output, and reports pass/fail.

The workflow: `pio test -e native` runs in under a second on your laptop and catches logic errors immediately. `pio test -e nanoatmega328` runs on real hardware when available. Proteus validates the complete electromechanical behavior. Each layer catches different classes of bugs.

## The complete workflow from code to deployment

For a team already running Proteus 9 with full mixed-signal simulation, the optimal development cycle looks like this:

```
Write code (VS Code + PlatformIO)
    ↓
pio run → compile → .pio/build/nanoatmega328/firmware.hex
    ↓                          ↓
pio test -e native     Load .hex into Proteus 9
(unit tests, <1 sec)   (full circuit simulation with
    ↓                   virtual oscilloscope, H-bridge,
    ↓                   motor models, PWM verification)
    ↓                          ↓
git push → GitHub Actions CI   pio run -t upload
(compile + native tests)       (flash real Arduino Nano)
```

**Adding another simulation layer on top of Proteus offers diminishing returns.** Wokwi lacks H-bridge and DC motor models. SimAVR lacks Phase Correct PWM. Neither provides analog waveform analysis. The one scenario where adding Wokwi makes sense: if team members need to test firmware logic on machines where Proteus isn't installed (it's Windows-only and license-limited), Wokwi in VS Code provides a quick visual sanity check.

The genuine productivity gains come from the supporting infrastructure. Set up **GitHub Actions** with PlatformIO to verify compilation and run native tests on every push — a 15-minute setup that prevents broken builds from reaching teammates. Pin library versions in `platformio.ini` to eliminate "works on my machine" problems. Use this project structure:

```
motor-control-project/
├── platformio.ini           # Build config (tracked in Git)
├── src/main.cpp             # Entry point: setup()/loop()
├── include/config.h         # Pin definitions, constants
├── lib/
│   ├── PIDController/       # Pure math, no Arduino deps → testable natively
│   ├── MotorDriver/         # H-bridge control via Arduino GPIO
│   └── Encoder/             # Encoder reading via interrupts
├── test/
│   ├── test_native/         # GoogleTest + ArduinoFake (desktop)
│   └── test_embedded/       # Unity tests (on-device)
├── proteus/
│   └── motor_circuit.pdsprj # Proteus project (XML-based, diff-friendly)
└── .github/workflows/ci.yml # CI pipeline
```

## Conclusion

The team's existing Proteus 9 setup is the single most valuable tool in the stack — **protect it and keep it central**. No free or open-source simulator can replicate its mixed-signal co-simulation for motor control. The real improvements are upstream: PlatformIO replaces Arduino IDE with reproducible builds, deterministic `.hex` output paths for Proteus, and professional project structure. Dual-target testing with GoogleTest and ArduinoFake catches logic bugs in under a second without any hardware or simulation. GitHub Actions CI ensures the build never breaks silently.

On the ARM question: it's a terminology error. ATmega328P is AVR, full stop. The teammate likely encountered documentation for one of Arduino's five ARM-based Nano variants or for STM32 motor control platforms. Correcting this misunderstanding early prevents the team from chasing irrelevant toolchain configurations. The correct cross-compilation target is `avr-gcc -mmcu=atmega328p`, and the entire Arduino/PlatformIO ecosystem handles this transparently.

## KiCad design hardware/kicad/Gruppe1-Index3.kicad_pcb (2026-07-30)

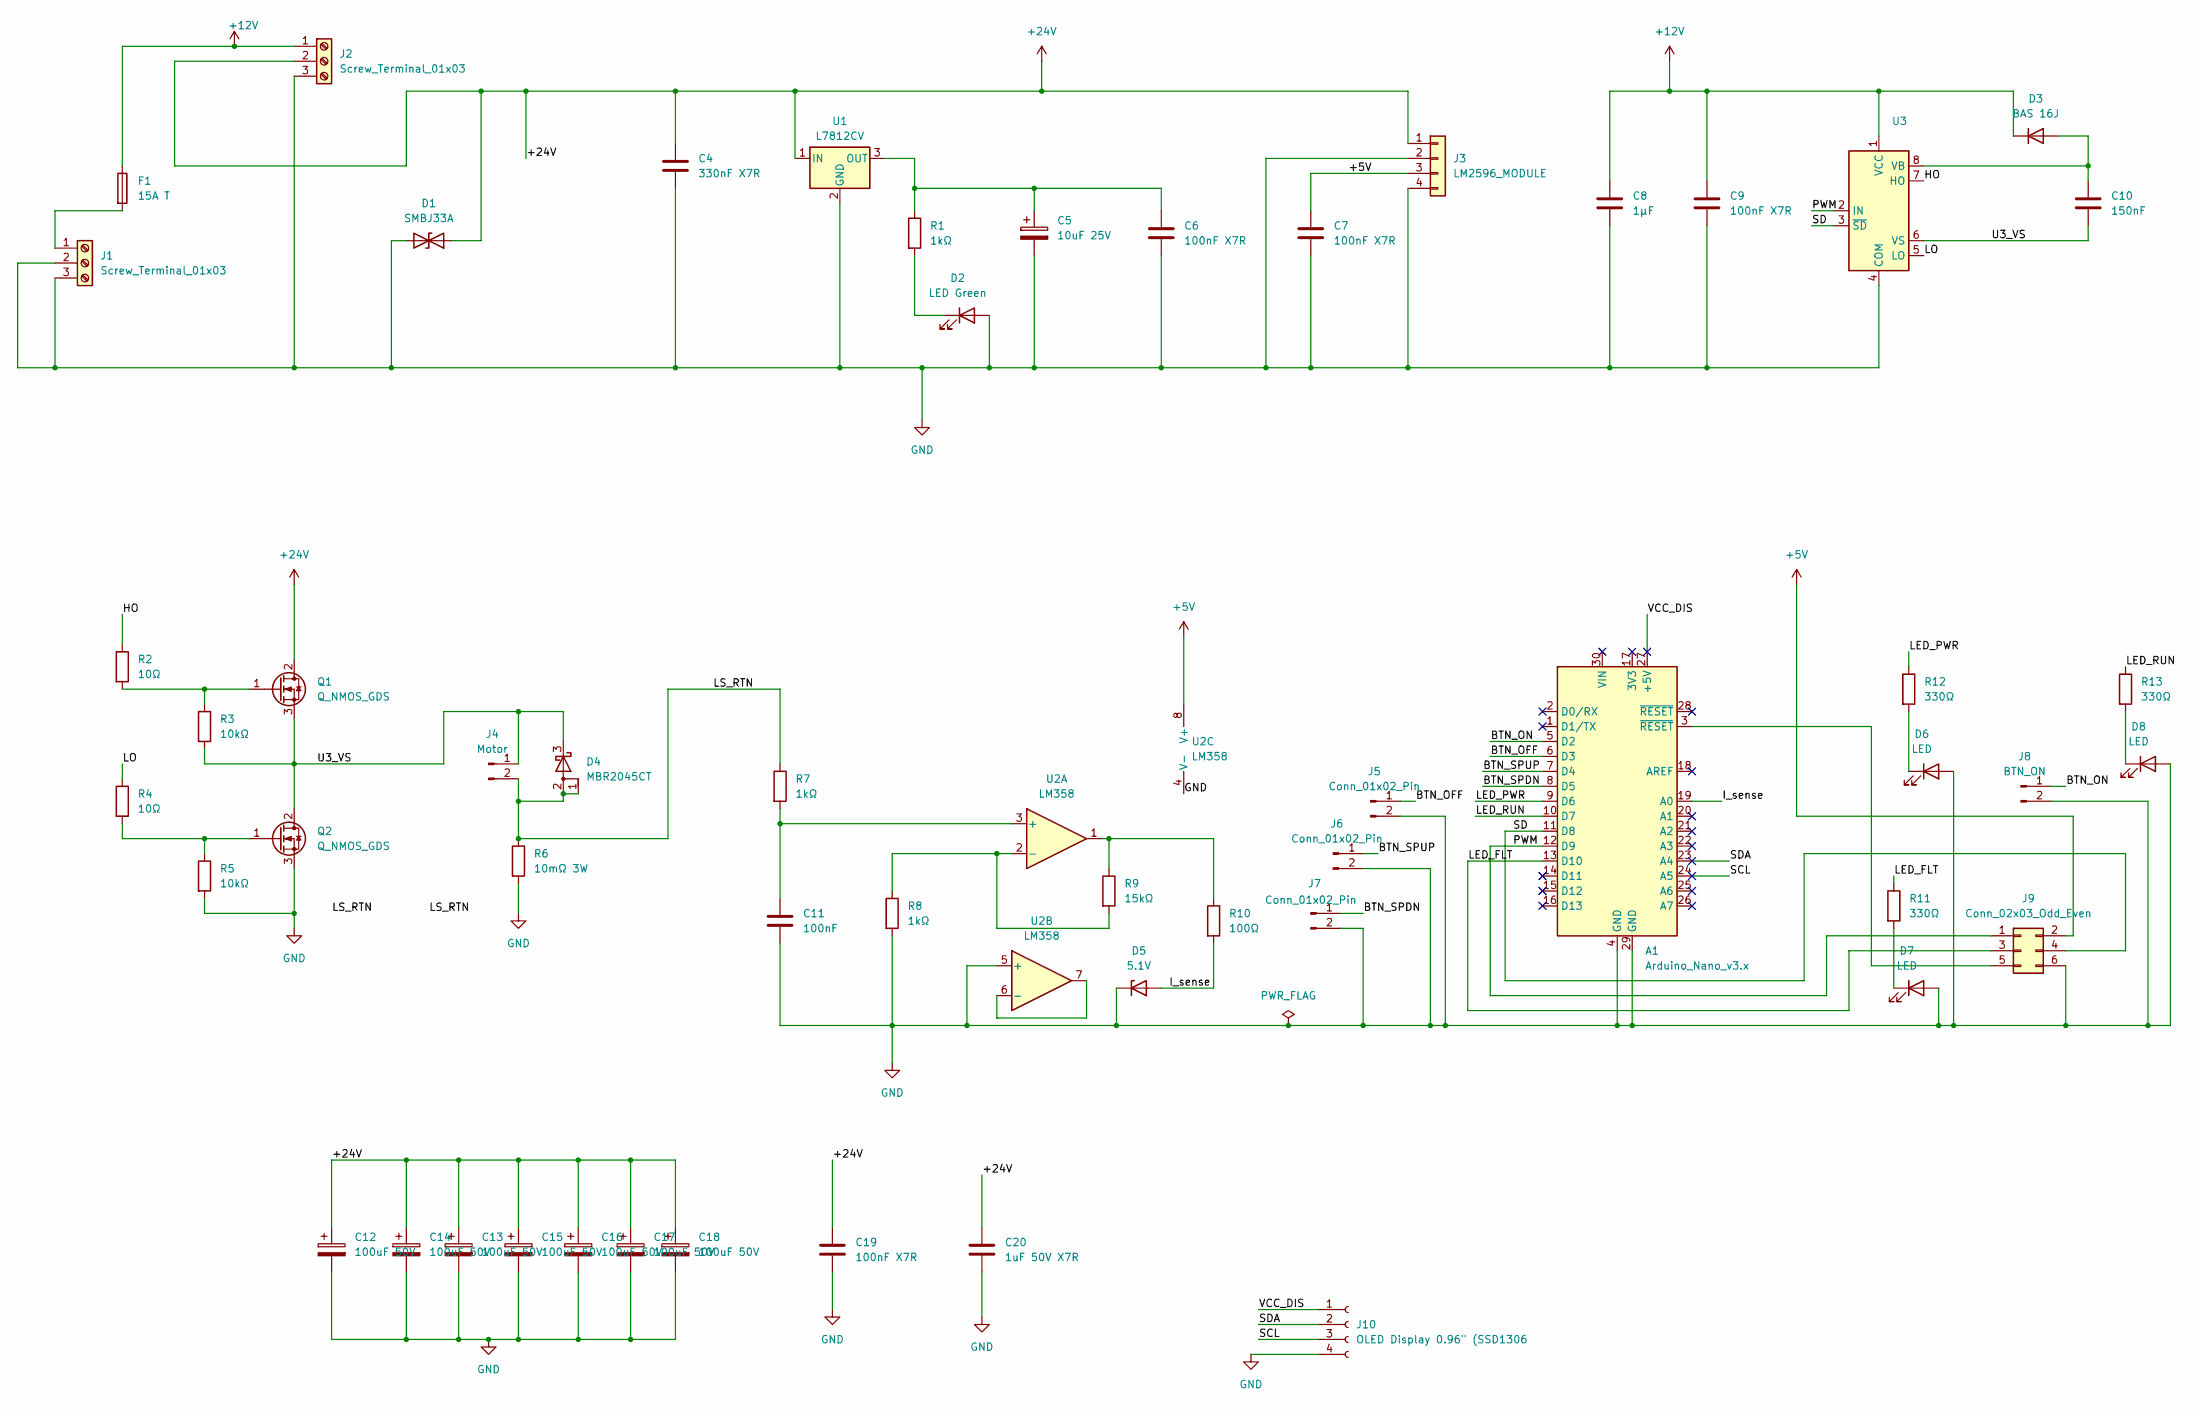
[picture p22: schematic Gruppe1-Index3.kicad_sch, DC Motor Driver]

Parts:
A1: Arduino_Nano_v3.x; Arduino_Nano
C4: 330nF X7R; C_1206_3216Metric
C5: 10uF 25V; C_1206_3216Metric
C6, C7, C9, C19: 100nF X7R; C_1206_3216Metric
C8: 1µF; C_1206_3216Metric
C10: 150nF; C_1206_3216Metric
C11: 100nF; C_1206_3216Metric
C12, C13, C14, C15, C16, C17, C18: 100uF 50V; CP_Elec_10x10.5
C20: 1uF 50V X7R; C_1206_3216Metric
D1: SMBJ33A; D_SMA-SMB_Universal_Handsoldering
D2: LED Green; LED_1206_3216Metric_Pad1.42x1.75mm_HandSolder
D3: BAS 16J; D_SOD-323F
D4: MBR2045CT; TO-263-3_TabPin2
D5: 5.1V; D_MiniMELF_Handsoldering
D6, D7, D8: LED; LED_1206_3216Metric_Pad1.42x1.75mm_HandSolder
F1: 15A T; Fuseholder_Cylinder-5x20mm_Stelvio-Kontek_PTF78_Horizontal_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
J1, J2: Screw_Terminal_01x03; TerminalBlock_Phoenix_PT-1,5-3-5.0-H_1x03_P5.00mm_Horizontal
J3: LM2596_MODULE; PinHeader_1x04_P2.54mm_Vertical
J4: Motor; TerminalBlock_Phoenix_MKDS-1,5-2-5.08_1x02_P5.08mm_Horizont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
J5, J6, J7: Conn_01x02_Pin; PinHeader_1x02_P2.54mm_Vertical
J8: BTN_ON; PinHeader_1x02_P2.54mm_Vertical
J9: Conn_02x03_Odd_Even; PinHeader_2x03_P2.54mm_Vertical
J10: OLED Display 0.96" (SSD1306; PinHeader_1x04_P2.54mm_Vertical
Q1, Q2: Q_NMOS_GDS; TO-263-3_TabPin2
R1, R7, R8: 1kΩ; R_0603_1608Metric_Pad0.98x0.95mm_HandSolder
R2, R4: 10Ω; R_0805_2012Metric_Pad1.20x1.40mm_HandSolder
R3, R5: 10kΩ; R_1206_3216Metric_Pad1.30x1.75mm_HandSolder
R6: 10mΩ 3W; R_Axial_Power_L20.0mm_W6.4mm_P25.40mm
R9: 15kΩ; R_1206_3216Metric_Pad1.30x1.75mm_HandSolder
R10: 100Ω; R_1206_3216Metric_Pad1.30x1.75mm_HandSolder
R11, R12, R13: 330Ω; R_1206_3216Metric_Pad1.30x1.75mm_HandSolder
U1: L7812CV; TO-220-3_Vertical
U2: LM358; DIP-8_W7.62mm
U3: IR2104; DIP-8_W7.62mm

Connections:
+5V: C7.1, J3.3, J9.2, U2.8 (V+)
+12V: C8.1, C9.1, D3.1 (K), F1.1, J2.1, U3.1 (VCC)
+24V: C4.1, C12.1, C13.1, C14.1, C15.1, C16.1, C17.1, C18.1, C19.1, C20.1, D1.1 (A1), J2.2, J3.1, Q1.2 (D), U1.1 (IN)
/BTN_OFF: A1.6 (D3), J5.1
/BTN_ON: A1.5 (D2), J8.1
/BTN_SPDN: A1.8 (D5), J7.1
/BTN_SPUP: A1.7 (D4), J6.1
/HO: R2.1, U3.7 (HO)
/I_sense: A1.19 (A0), D5.2 (A), R10.2
/LED_FLT: A1.13 (D10), J9.3, R11.1
/LED_PWR: A1.9 (D6), R12.1
/LED_RUN: A1.10 (D7), R13.1
/LO: R4.1, U3.5 (LO)
/LS_RTN: D4.1 (A), D4.2 (A), J4.2, R6.1, R7.1
/PWM: A1.12 (D9), J9.1, U3.2 (IN)
/SCL: A1.24 (A5), J10.3
/SD: A1.11 (D8), J9.4, U3.3 (~SD)
/SDA: A1.23 (A4), J10.2
/U3_VS: C10.2, D4.3 (K), J4.1, Q1.3 (S), Q2.2 (D), R3.2, U3.6 (VS)
/VCC_DIS: A1.27 (+5V), J10.1
GND: A1.4 (GND), A1.29 (GND), C4.2, C5.2, C6.2, C7.2, C8.2, C9.2, C11.2, C12.2, C13.2, C14.2, C15.2, C16.2, C17.2, C18.2, C19.2, C20.2, D1.2 (A2), D2.2 (A), D5.1 (K), D6.2 (A), D7.2 (A), D8.2 (A), J1.2, J1.3, J2.3, J3.2, J3.4, J5.2, J6.2, J7.2, J8.2, J9.6, J10.4, Q2.3 (S), R5.2, R6.2, R8.2, U1.2 (GND), U2.4 (V-), U2.5 (+), U3.4 (COM)
unnamed: D2.1 (K), R1.2
unnamed: C10.1, D3.2 (A), U3.8 (VB)
unnamed: D6.1 (K), R12.2
unnamed: D7.1 (K), R11.2
unnamed: D8.1 (K), R13.2
unnamed: F1.2, J1.1
unnamed: A1.3 (~RESET), J9.5
unnamed: Q1.1 (G), R2.2, R3.1
unnamed: Q2.1 (G), R4.2, R5.1
unnamed: R9.1, R10.1, U2.1
unnamed: C5.1, C6.1, R1.1, U1.3 (OUT)
unnamed: C11.1, R7.2, U2.3 (+)
unnamed: R8.1, R9.2, U2.2 (-)
unnamed: U2.6 (-), U2.7

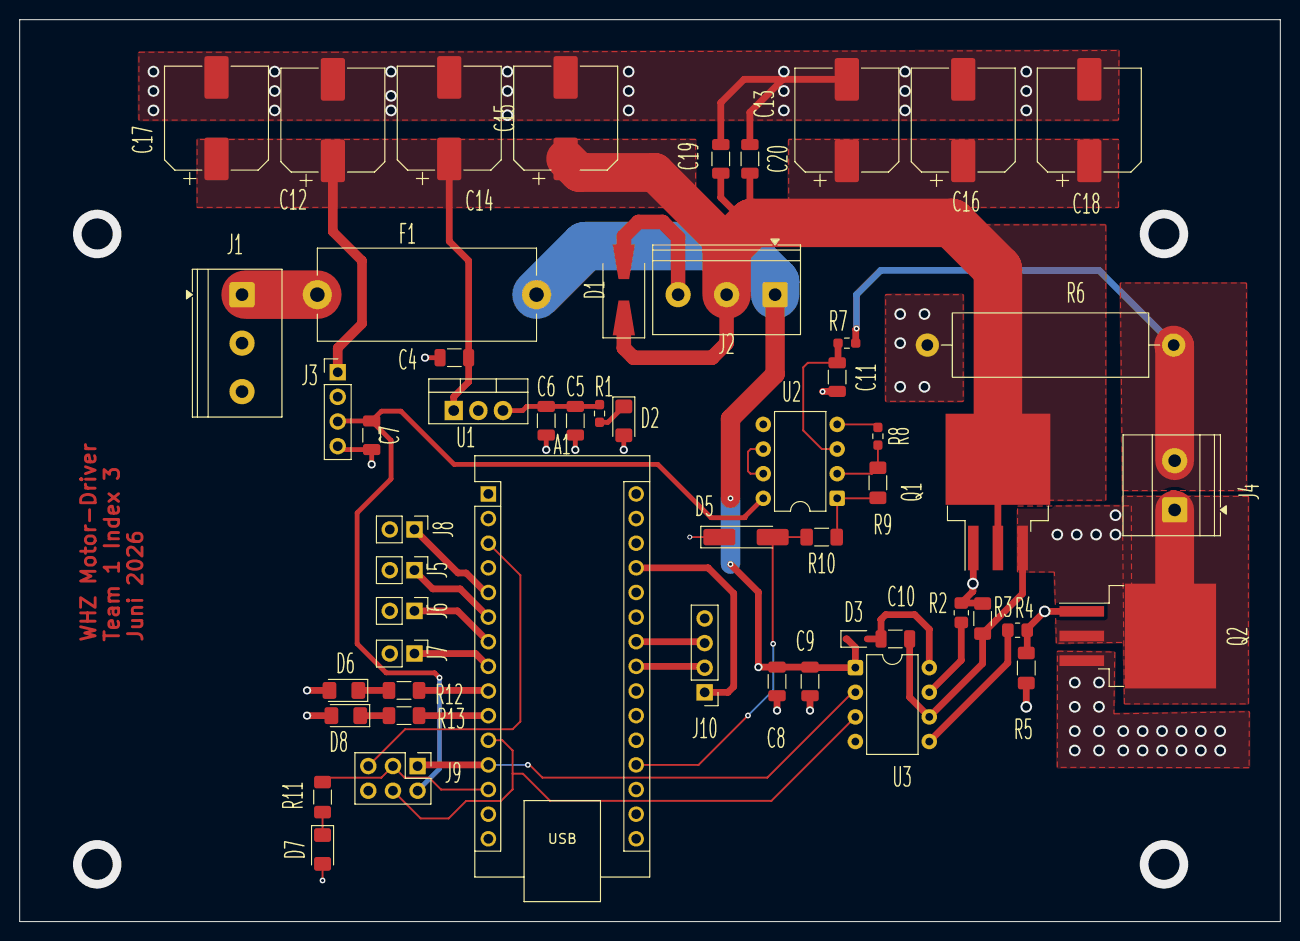
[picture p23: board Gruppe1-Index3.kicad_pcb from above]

Board: 2 copper layers, 130.0 x 93.0 mm, 55 parts (1 on the bottom side), 35 nets.

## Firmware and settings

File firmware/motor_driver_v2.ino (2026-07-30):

/*
 * motor_driver_v2.ino
 * 24V / 250W Brushed DC Motor Driver — IR2104 Half-Bridge + IRFZ44N
 *
 * Team 1 — ELT10140 Electric Drive Systems
 * WHZ Westsächsische Hochschule Zwickau, SoSe 2026
 *
 * === PROJECT REQUIREMENT COMPLIANT ===
 * Main switch (latching) + 4 push buttons:
 *   ON / OFF / Speed Up / Speed Down
 *
 * PIN ASSIGNMENTS (Arduino Nano / ATmega328P)
 * ─────────────────────────────────────────────────────────────
 *  D9   PB1 / OC1A  → IR2104 IN  (20 kHz PWM output)
 *  D8   PB0         → IR2104 SD  (HIGH = driver enabled)
 *  A0   PC0 / ADC0  → LM358 output (amplified shunt voltage)
 *  D2   PD2         → ON button        (momentary, to GND)
 *  D3   PD3         → OFF button       (momentary, to GND)
 *  D4   PD4         → Speed Up button  (momentary, to GND)
 *  D5   PD5         → Speed Down button(momentary, to GND)
 *  D10  PB2         → Main Switch      (latching SWITCH, to GND)
 *  D6   PD6         → Green LED via 330Ω (motor running)
 *  D7   PD7         → Red LED   via 330Ω (fault indicator)
 *
 * TIMER1 FAST PWM MODE 14
 *   ICR1 = 799  →  f_PWM = 16 MHz / (1 × 800) = 20 000 Hz
 *   OCR1A range 0–799 (0–100 % duty cycle)
 *   Max duty clamped to 759 (95 %) so bootstrap cap recharges every cycle
 *
 * CURRENT SENSING
 *   Shunt R6 = 10 mΩ, LM358 gain = 16 (1 kΩ + 15 kΩ)
 *   V_out = I_motor × 0.010 × 16 = 0.16 × I_motor
 *   ADC count = I_motor × (0.16 / 5.0) × 1023 ≈ I_motor × 32.74
 *   20 A threshold → ADC ≈ 655
 *
 * STATE MACHINE
 *   OFF ──[ON btn + switch]──► STARTING ──[ramp done]──► RUNNING
 *    ▲                              │                        │
 *    │                              └─── overcurrent ────────┤
 *    │                                                       ▼
 *    └── BRAKING ◄──[OFF btn]────────────────────────── FAULT
 *
 * NOTE: This source file corresponds to the compiled HEX loaded in
 *       the Proteus VSM simulation (motor_driver.hex).
 *       To rebuild: Arduino IDE → Board: Arduino Nano (ATmega328P),
 *       Processor: ATmega328P (Old Bootloader), 16 MHz.
 */

// ═══════════════════ PIN DEFINITIONS ═══════════════════
#define PWM_PIN       9    // OC1A — Timer1 PWM → IR2104 IN
#define SD_PIN        8    // IR2104 SD (HIGH = enabled, LOW = shutdown)
#define CURRENT_PIN   A0   // LM358 output → ATmega ADC0

#define BTN_ON        2    // ON button        (active LOW, INPUT_PULLUP)
#define BTN_OFF       3    // OFF button       (active LOW, INPUT_PULLUP)
#define BTN_SPEED_UP  4    // Speed Up button  (active LOW, INPUT_PULLUP)
#define BTN_SPEED_DN  5    // Speed Down button(active LOW, INPUT_PULLUP)
#define MAIN_SWITCH   10   // Latching switch  (active LOW, INPUT_PULLUP)

#define LED_RUN       6    // Green LED — motor running
#define LED_FAULT     7    // Red LED   — fault state

// ═══════════════════ CONSTANTS ═══════════════════
#define PWM_TOP        799   // ICR1 TOP → exactly 20 kHz at 16 MHz / 1 prescaler
#define DUTY_MAX       759   // 95 % of 799 — bootstrap capacitor must recharge

#define NUM_SPEED_LEVELS  10
#define DEFAULT_LEVEL      5           // Start at level 5 = 50 % duty
#define SPEED_STEP        (PWM_TOP / NUM_SPEED_LEVELS)  // ≈ 80 counts per level

#define RAMP_TIME_MS   2000  // Soft-start: ramp from 0 to target over 2 s
#define BRAKE_TIME_MS  1000  // Braking:    ramp from target to 0 over 1 s

#define AMP_GAIN       16.0
#define SHUNT_OHM      0.010
#define VREF_V         5.0
#define ADC_BITS       1023
#define OC_THRESHOLD   655   // ADC count corresponding to 20 A overcurrent trip
#define STALL_MS       1000  // Stall = OC sustained for > 1 second

#define DEBOUNCE_MS    50

// ═══════════════════ STATE MACHINE ═══════════════════
enum MotorState { STATE_OFF, STATE_STARTING, STATE_RUNNING,
                  STATE_BRAKING, STATE_FAULT };
MotorState currentState = STATE_OFF;

// ═══════════════════ GLOBAL VARIABLES ═══════════════════
// Speed
int  speedLevel   = DEFAULT_LEVEL;
uint16_t targetDuty = DEFAULT_LEVEL * SPEED_STEP;  // ≈ 400 (50 %)

// State timing
unsigned long stateEntryTime = 0;

// Overcurrent / stall
unsigned long stallStartTime = 0;
bool          stallActive    = false;

// Current sensing
float filteredCurrent = 0.0;
int   zeroOffset      = 0;    // Calibrated at power-on

// LED blink (fault state)
unsigned long lastBlinkTime = 0;
bool          blinkState    = false;

// Button debounce — indexes: 0=ON, 1=OFF, 2=SpeedUp, 3=SpeedDn
#define NUM_BUTTONS 4
unsigned long debounceTime[NUM_BUTTONS] = {0, 0, 0, 0};
bool lastBtnState[NUM_BUTTONS]  = {HIGH, HIGH, HIGH, HIGH};
bool btnTriggered[NUM_BUTTONS]  = {false, false, false, false};

// ═══════════════════ TIMER1 SETUP ═══════════════════
void setupTimer1_20kHz() {
    DDRB  |= (1 << PB1);   // Pin 9 = output

    TCCR1A = 0;
    TCCR1B = 0;
    TCNT1  = 0;

    // Fast PWM Mode 14 (WGM13:WGM12:WGM11:WGM10 = 1110)
    // Non-inverting on OC1A, no prescaler (CS10 = 1)
    TCCR1A = (1 << COM1A1) | (1 << WGM11);
    TCCR1B = (1 << WGM13)  | (1 << WGM12) | (1 << CS10);

    ICR1  = PWM_TOP;
    OCR1A = 0;             // Start at 0 % duty
}

void setDuty(uint16_t duty) {
    if (duty > DUTY_MAX) duty = DUTY_MAX;
    OCR1A = duty;
}

// ═══════════════════ CURRENT SENSING ═══════════════════
void calibrateCurrentSensor() {
    long sum = 0;
    for (int i = 0; i < 64; i++) {
        sum += analogRead(CURRENT_PIN);
        delay(1);
    }
    zeroOffset = (int)(sum / 64);
}

float readCurrent() {
    int raw = analogRead(CURRENT_PIN) - zeroOffset;
    if (raw < 0) raw = 0;
    // V_adc = raw × (VREF / 1023)
    // I = V_adc / (AMP_GAIN × SHUNT_OHM)
    float current = (float)raw * (VREF_V / ADC_BITS) / (AMP_GAIN * SHUNT_OHM);
    // EMA filter — α = 0.1 (matches Simulink PT1 discretisation)
    filteredCurrent = 0.1f * current + 0.9f * filteredCurrent;
    return filteredCurrent;
}

// ═══════════════════ BUTTON DEBOUNCE ═══════════════════
// Fire exactly once per physical press; reset on release.
bool readButton(int index, int pin) {
    bool reading = digitalRead(pin);

    // Released — allow next press
    if (reading == HIGH) {
        btnTriggered[index] = false;
        lastBtnState[index] = HIGH;
        return false;
    }

    // Falling edge — start debounce timer
    if (lastBtnState[index] == HIGH && reading == LOW) {
        debounceTime[index] = millis();
        lastBtnState[index] = LOW;
    }

    // Debounce settled, not yet triggered
    if (!btnTriggered[index] &&
        (millis() - debounceTime[index]) > DEBOUNCE_MS) {
        btnTriggered[index] = true;
        return true;
    }

    return false;
}

// ═══════════════════ FAULT ENTRY ═══════════════════
void enterFault() {
    digitalWrite(SD_PIN, LOW);
    setDuty(0);
    currentState = STATE_FAULT;
    stateEntryTime = millis();
    stallActive = false;
    filteredCurrent = 0.0f;
    digitalWrite(LED_RUN, LOW);
}

// ═══════════════════ SETUP ═══════════════════
void setup() {
    // Output pins
    pinMode(SD_PIN,   OUTPUT);
    pinMode(LED_RUN,  OUTPUT);
    pinMode(LED_FAULT, OUTPUT);
    digitalWrite(SD_PIN,    LOW);
    digitalWrite(LED_RUN,   LOW);
    digitalWrite(LED_FAULT, LOW);

    // Input pins (active LOW, internal pull-up)
    pinMode(BTN_ON,       INPUT_PULLUP);
    pinMode(BTN_OFF,      INPUT_PULLUP);
    pinMode(BTN_SPEED_UP, INPUT_PULLUP);
    pinMode(BTN_SPEED_DN, INPUT_PULLUP);
    pinMode(MAIN_SWITCH,  INPUT_PULLUP);

    // ADC reference = AVCC (tied to +5 V on PCB via AREF pin)
    analogReference(DEFAULT);

    setupTimer1_20kHz();
    calibrateCurrentSensor();

    // Serial for debugging (optional — disable in release)
    // Serial.begin(115200);
}

// ═══════════════════ MAIN LOOP ═══════════════════
void loop() {
    unsigned long now = millis();

    // Read main switch and buttons
    bool switchOn    = (digitalRead(MAIN_SWITCH) == LOW);
    bool onPressed   = readButton(0, BTN_ON);
    bool offPressed  = readButton(1, BTN_OFF);
    bool upPressed   = readButton(2, BTN_SPEED_UP);
    bool downPressed = readButton(3, BTN_SPEED_DN);

    // ── Global: main switch OFF → force everything off ──
    if (!switchOn && currentState != STATE_OFF && currentState != STATE_FAULT) {
        setDuty(0);
        digitalWrite(SD_PIN, LOW);
        currentState = STATE_OFF;
    }

    // ── Overcurrent check (every state except OFF/FAULT) ──
    if (currentState == STATE_STARTING || currentState == STATE_RUNNING ||
        currentState == STATE_BRAKING) {
        float I = readCurrent();
        int rawADC = analogRead(CURRENT_PIN) - zeroOffset;
        if (rawADC < 0) rawADC = 0;

        if (rawADC > OC_THRESHOLD) {
            // Instantaneous overcurrent
            enterFault();
            return;
        }
        if (I > 20.0f) {
            // Stall detection: sustained overcurrent
            if (!stallActive) {
                stallActive = true;
                stallStartTime = now;
            } else if ((now - stallStartTime) >= STALL_MS) {
                enterFault();
                return;
            }
        } else {
            stallActive = false;
        }
    }

    // ── State machine ──
    switch (currentState) {

        // ─── OFF ───────────────────────────────────────────
        case STATE_OFF:
            setDuty(0);
            digitalWrite(SD_PIN, LOW);
            digitalWrite(LED_RUN,   LOW);
            digitalWrite(LED_FAULT, LOW);

            if (switchOn && onPressed) {
                targetDuty = speedLevel * SPEED_STEP;
                if (targetDuty > DUTY_MAX) targetDuty = DUTY_MAX;
                currentState   = STATE_STARTING;
                stateEntryTime = now;
                stallActive    = false;
                filteredCurrent = 0.0f;
                digitalWrite(SD_PIN, HIGH);   // Enable IR2104
            }
            break;

        // ─── STARTING (soft-start ramp) ────────────────────
        case STATE_STARTING: {
            unsigned long elapsed = now - stateEntryTime;
            uint16_t rampDuty;

            if (elapsed >= RAMP_TIME_MS) {
                rampDuty = targetDuty;
                setDuty(rampDuty);
                currentState = STATE_RUNNING;
            } else {
                // Linear ramp: 0 → targetDuty over RAMP_TIME_MS
                rampDuty = (uint16_t)((float)targetDuty * elapsed / RAMP_TIME_MS);
                setDuty(rampDuty);
            }
            digitalWrite(LED_RUN, HIGH);

            if (offPressed) {
                currentState   = STATE_BRAKING;
                stateEntryTime = now;
            }
            break;
        }

        // ─── RUNNING ───────────────────────────────────────
        case STATE_RUNNING:
            setDuty(targetDuty);
            digitalWrite(LED_RUN, HIGH);

            // Speed Up
            if (upPressed && speedLevel < NUM_SPEED_LEVELS) {
                speedLevel++;
                targetDuty = speedLevel * SPEED_STEP;
                if (targetDuty > DUTY_MAX) targetDuty = DUTY_MAX;
            }
            // Speed Down
            if (downPressed && speedLevel > 1) {
                speedLevel--;
                targetDuty = speedLevel * SPEED_STEP;
            }
            // Stop
            if (offPressed || !switchOn) {
                currentState   = STATE_BRAKING;
                stateEntryTime = now;
            }
            break;

        // ─── BRAKING (ramp down) ───────────────────────────
        case STATE_BRAKING: {
            unsigned long elapsed = now - stateEntryTime;
            uint16_t brakeDuty;

            if (elapsed >= BRAKE_TIME_MS) {
                setDuty(0);
                digitalWrite(SD_PIN, LOW);
                digitalWrite(LED_RUN, LOW);
                currentState = STATE_OFF;
            } else {
                // Linear ramp down from targetDuty to 0
                brakeDuty = (uint16_t)((float)targetDuty *
                            (1.0f - (float)elapsed / BRAKE_TIME_MS));
                setDuty(brakeDuty);
                digitalWrite(LED_RUN, HIGH);
            }
            break;
        }

        // ─── FAULT ─────────────────────────────────────────
        case STATE_FAULT:
            setDuty(0);
            digitalWrite(SD_PIN, LOW);
            digitalWrite(LED_RUN, LOW);

            // Blink red LED at 2 Hz
            if ((now - lastBlinkTime) >= 250) {
                lastBlinkTime = now;
                blinkState = !blinkState;
                digitalWrite(LED_FAULT, blinkState);
            }

            // Clear fault: cycle main switch (OFF then ON) then press ON
            if (!switchOn) {
                // Switch is off — waiting for it to be turned on again
                // Fault cleared only when switch toggled back
                ;
            } else if (onPressed) {
                digitalWrite(LED_FAULT, LOW);
                blinkState    = false;
                currentState  = STATE_OFF;
                filteredCurrent = 0.0f;
                stallActive   = false;
            }
            break;
    }
}

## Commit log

2026-04-06 Initial commit: ELT10140 Electric Drive Systems - 24V 250W DC Motor Driver
2026-07-30 Add firmware, KiCad PCB, Gerbers, Proteus simulation, Simulink model, report and BOM; restructure repository; remove WHZ course material
    [BOM ElectricDriveSystems 1.1.xlsx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]
2026-07-30 Rename BOM file: remove spaces from filename
    [BOM_ElectricDriveSystems_1_1.xlsx]
